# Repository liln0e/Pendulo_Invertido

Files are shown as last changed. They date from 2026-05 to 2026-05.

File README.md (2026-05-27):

# Péndulo Invertido Autocontrolado

Proyecto académico de un **péndulo invertido autocontrolado (self-balancing robot)** basado en **ESP32** y control **PID**, diseñado para mantener el equilibrio de forma autónoma mediante sensores inerciales y control en tiempo real.

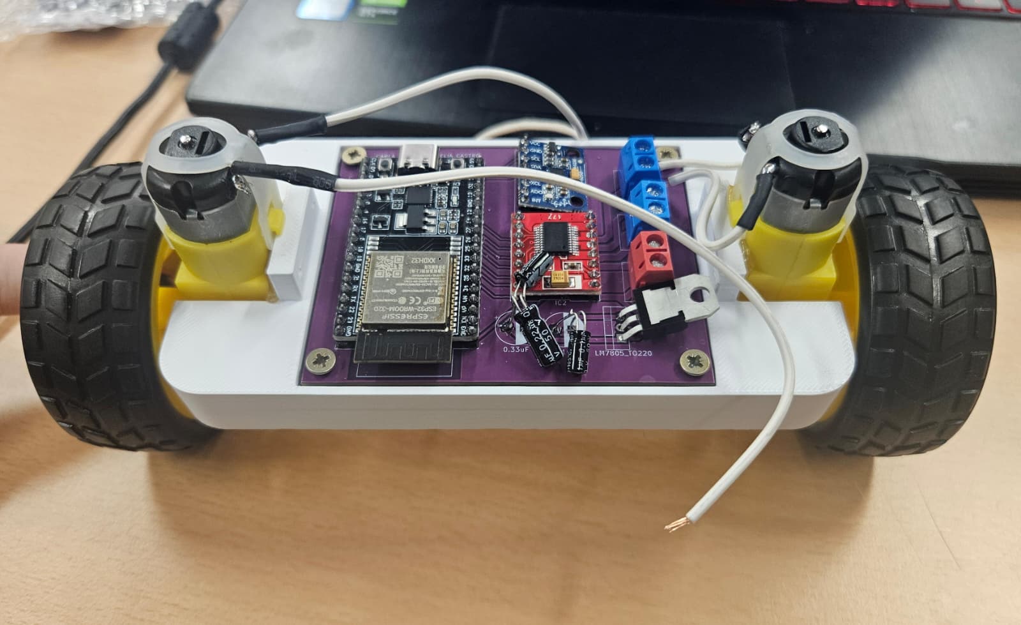
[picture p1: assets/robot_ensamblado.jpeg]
Robot ensamblado


---

## Descripción del proyecto

Este repositorio recoge el desarrollo de un **robot autoequilibrado de dos ruedas**, integrando diseño mecánico, electrónica y programación embebida.

El sistema utiliza un **ESP32** como unidad principal de control, un sensor **MPU6050** para estimar la inclinación y un controlador **PID** encargado de actuar sobre los motores para mantener el equilibrio.

El proyecto incluye:

- Diseño mecánico del chasis mediante modelado 3D.
- Diseño electrónico mediante una PCB personalizada en **KiCad**.
- Programación embebida sobre **ESP32**.
- Implementación de control **PID** para estabilidad del sistema.

---

## Tecnologías utilizadas

### Hardware

- ESP32 DevKitC  
- MPU6050  
- TB6612FNG  
- LM7805  
- Motores DC con reductora  
- PCB personalizada  
- Chasis impreso en 3D  

### Software y herramientas

- ESP32 / Arduino Framework  
- KiCad  
- Fusion 360  
- Control PID discreto  
- Filtro complementario  

---

## Estructura del repositorio

```txt
Proyecto_Pendulo_Invertido/
│
├── README.md
├── costes.md
├── documentacion.md
│
├── assets/
├── electronica/
├── mecanica/
└── software/
```

### Documentación principal

- [`documentacion.md`](./documentacion.md) → Explicación técnica completa del sistema.
- [`costes.md`](./costes.md) → Coste aproximado de materiales y componentes.

### Carpetas del proyecto

- [`electronica/`](./electronica/) → Diseño PCB y archivos de KiCad.
- [`mecanica/`](./mecanica/) → Diseño del chasis y fabricación.
- [`software/`](./software/) → Código del sistema de control.
- [`assets/`](./assets/) → Recursos visuales del proyecto.

---

## Integrantes del proyecto

### Carla Freire Muíño  
GitHub: [@carlafreeire](https://github.com/carlafreeire)

### Noelia Castro Rodríguez  
GitHub: [@liln0e](https://github.com/liln0e)

---

## Licencia

Proyecto desarrollado con fines académicos y educativos.

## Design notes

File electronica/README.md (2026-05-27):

# Diseño electrónico del péndulo invertido

Esta carpeta contiene los archivos del diseño electrónico del **péndulo invertido autocontrolado**, desarrollados en **KiCad**.

## Contenido

- `Pendulo_Inverso.kicad_sch` → Esquemático electrónico del sistema.
- `Pendulo_Inverso.kicad_pcb` → Diseño de la PCB.
- `Pendulo_Inverso.kicad_pro` → Proyecto completo de KiCad.

## Descripción

La electrónica integra los principales componentes del robot:

- **ESP32 DevKitC** como unidad de control.
- **MPU6050** para la medición de inclinación.
- **TB6612FNG** para el control de motores.
- **LM7805** para regulación de tensión.
- Conectores de alimentación y motores.

El diseño fue realizado sobre una **PCB personalizada** con el objetivo de reducir cableado, facilitar el ensamblaje y mejorar la integración del sistema.

La explicación técnica detallada puede consultarse en [`../documentacion.md`](../documentacion.md).

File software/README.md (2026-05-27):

# Software del péndulo invertido

Esta carpeta contiene el código fuente del **péndulo invertido autocontrolado**, desarrollado para ejecutarse sobre un **ESP32 DevKitC**.

## Contenido

- `PID_Basico.ino` → Implementación de un controlador PID discreto básico.
- `PID_IIR.ino` → Implementación del PID en forma de filtro IIR.
- `PID_Filtrado.ino` → Implementación del PID con filtrado en el término derivativo.

## Funcionalidades implementadas

- Lectura del sensor **MPU6050**.
- Estimación del ángulo de inclinación.
- Filtrado de señal mediante filtro complementario.
- Control PID discreto.
- Generación de señales para motores DC.
- Ajuste y depuración mediante monitor serie.

Durante el desarrollo se implementaron distintas versiones del controlador para comparar estabilidad, suavidad de respuesta y sensibilidad al ruido.

La arquitectura completa del sistema se describe en [`../documentacion.md`](../documentacion.md).

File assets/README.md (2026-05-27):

# Recursos visuales del proyecto

En esta carpeta se incluyen recursos visuales empleados para documentar el desarrollo del **péndulo invertido autocontrolado**, mostrando distintas fases del diseño electrónico, fabricación y ensamblaje del sistema.

## Contenido

Los siguientes archivos corresponden a material visual del proyecto:

- `esquematico_kicad.jpg` → Esquemático electrónico del sistema realizado en KiCad.
- `pcb_diseno_kicad.png` → Diseño de la PCB realizado en KiCad.
- `pcb_fabricada.jpeg` → PCB fabricada tras el proceso de producción.
- `montaje_componentes.jpeg` → Integración de los principales componentes electrónicos sobre el chasis.
- `robot_ensamblado.jpeg` → Estado del robot completamente ensamblado.

## Descripción

Los recursos visuales permiten documentar la evolución del proyecto desde el diseño electrónico hasta el montaje final del sistema.

Las imágenes incluidas muestran distintas etapas del desarrollo:

- Diseño del esquemático electrónico del sistema en KiCad, incluyendo el **ESP32**, el controlador de motores **TB6612FNG**, el sensor **MPU6050** y la etapa de alimentación.
- Diseño y distribución de componentes en la PCB.
- Fabricación de la placa electrónica.
- Integración de la electrónica sobre el chasis impreso en 3D.
- Ensamblaje del sistema completo con motores, ruedas y electrónica de control.

Este material se emplea como apoyo visual de la documentación técnica del proyecto y permite mostrar de forma clara el proceso de diseño, fabricación e integración del péndulo invertido.

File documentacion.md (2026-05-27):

# Documentación técnica del proyecto

Este documento recoge la información técnica general del proyecto de **péndulo invertido autocontrolado (self-balancing robot)**, incluyendo la arquitectura del sistema, el diseño mecánico, la electrónica y el software implementado para el control del robot.

El objetivo principal del sistema es mantener el equilibrio de forma autónoma mediante un controlador **PID**, capaz de corregir la inclinación del robot actuando sobre los motores en tiempo real.

---

# Arquitectura general del sistema

El robot implementa un sistema de control en lazo cerrado compuesto por las siguientes etapas:

1. **Captura de inclinación** mediante una unidad IMU (**MPU6050**).
2. **Estimación del ángulo** utilizando acelerómetro y giroscopio.
3. **Filtrado de señal** mediante un **filtro complementario**.
4. **Cálculo de la acción de control PID**.
5. **Actuación sobre los motores** para recuperar la posición vertical.

El flujo simplificado del sistema es el siguiente:

```txt
MPU6050
    ↓
Estimación del ángulo
    ↓
Filtro complementario
    ↓
Control PID
    ↓
Driver TB6612FNG
    ↓
Motores
    ↓
Corrección de la inclinación
```

El sistema realiza un procesamiento continuo de los datos de inclinación y ajusta dinámicamente la velocidad de los motores para compensar perturbaciones y mantener la estabilidad.

---

# Diseño mecánico

La parte mecánica del robot se diseñó con el objetivo de obtener una estructura **compacta, ligera y estable**, favoreciendo un **centro de gravedad bajo** para mejorar el comportamiento dinámico del sistema.

El chasis fue modelado en **Fusion 360** y fabricado mediante **impresión 3D**, permitiendo adaptar la geometría a las necesidades específicas del proyecto y facilitar la integración de los componentes electrónicos.

Durante el desarrollo se realizaron distintas iteraciones del diseño para optimizar:

- Distribución del peso.
- Posicionamiento de la electrónica.
- Integración de motores y ruedas.
- Robustez estructural.
- Facilidad de ensamblaje.

El diseño final permite alojar de forma compacta todos los elementos del sistema, manteniendo un acceso sencillo a la electrónica y facilitando futuras modificaciones.

---

# Diseño electrónico

La electrónica del robot fue diseñada sobre una **PCB personalizada desarrollada en KiCad**, permitiendo integrar los distintos módulos del sistema en una única placa.

Los componentes principales utilizados son:

- **ESP32 DevKitC** → Unidad principal de control.
- **MPU6050** → Sensor IMU para estimación de inclinación.
- **TB6612FNG** → Driver de control de motores.
- **LM7805** → Regulación de tensión.
- Conectores de alimentación y motores.

El diseño electrónico se planteó con varios objetivos:

- Reducir el cableado del sistema.
- Mejorar la integración entre componentes.
- Facilitar el ensamblaje del robot.
- Incrementar la robustez del conjunto.

La PCB integra alimentación, control y conexiones de potencia necesarias para el funcionamiento autónomo del sistema.

---

# Diseño software

El software del robot se ejecuta sobre una **ESP32**, encargándose de procesar la información procedente del sensor y aplicar la lógica de control necesaria para mantener el equilibrio.

Las funcionalidades principales implementadas son:

- Lectura del sensor **MPU6050**.
- Estimación del ángulo de inclinación.
- Aplicación de un **filtro complementario**.
- Implementación del **control PID discreto**.
- Generación de señales de control para los motores.
- Ajuste y depuración mediante monitor serie.

Durante el desarrollo se implementaron distintas versiones del controlador PID con el objetivo de comparar comportamiento, estabilidad y sensibilidad al ruido del sistema.

La lógica simplificada del software es:

```txt
Lectura IMU
    ↓
Estimación de inclinación
    ↓
Filtro complementario
    ↓
Cálculo PID
    ↓
Control de motores
    ↓
Corrección del equilibrio
```

---

# Organización del repositorio

El proyecto se organiza en distintas carpetas para separar la documentación y facilitar el desarrollo:

```txt
Proyecto_Pendulo_Invertido/
│
├── README.md
├── costes.md
├── documentacion.md
│
├── assets/
├── electronica/
├── mecanica/
└── software/
```

Cada carpeta contiene información específica del proyecto:

- `electronica/` → Diseño PCB, esquemáticos y archivos de KiCad.
- `mecanica/` → Modelado 3D y archivos de fabricación.
- `software/` → Código fuente y pruebas del controlador.
- `assets/` → Recursos visuales del proyecto.

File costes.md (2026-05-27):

# Costes y materiales

En este documento se recoge el coste aproximado de los materiales empleados para la construcción del robot tipo **péndulo invertido (self-balancing robot)**.

El objetivo del proyecto fue desarrollar un sistema funcional utilizando **componentes económicos y fácilmente accesibles**, complementados con recursos proporcionados por la universidad, como la impresión 3D y parte del material electrónico.

---

# Desglose de materiales

| Componente | Cantidad | Precio (€) | Comentarios |
|---|---|---|---|
| **ESP32 DevKitC** | 1 | 4,49 | Microcontrolador principal |
| **MPU6050 (GY-521)** | 1 | 1,81 | Sensor IMU (acelerómetro + giroscopio) |
| **Motores TT + ruedas** | 2 motores + 2 ruedas | 3,99 | Sistema de tracción |
| **Driver TB6612FNG** | 1 | Incluido | Control de motores |
| **LM7805** | 1 | 1,45 | Regulador de tensión |
| **PCB personalizada (JLCPCB)** | 1 | ≈ 2,87 | Coste real aproximado por unidad |
| **Pila plana 3R12 4,5 V** | 1 | 5,99 | Alimentación del sistema |
| **Condensador 0.1 µF** | 1 | 0,00 | Material de laboratorio |
| **Condensador equivalente 0.33 µF** | 1 conjunto | 0,00 | Implementado con 0.22 µF + 0.11 µF |
| **Borneras de 2 pines** | 3 | 0,00 | Material de laboratorio |
| **Chasis impreso 3D** | 1 | 0,00 | Fabricado en la universidad |

---

# Coste total aproximado

Considerando únicamente los materiales realmente utilizados en el robot:

**Coste estimado total del proyecto:** **≈ 20,60 €**

> Este valor no incluye material proporcionado gratuitamente por la universidad ni costes indirectos de fabricación.

---

# Notas

- La **PCB fue diseñada específicamente para el proyecto** y fabricada mediante **JLCPCB**. El coste reflejado corresponde a una unidad individual del pedido realizado.
- El condensador de **0.33 µF no estaba disponible**, por lo que se implementó correctamente conectando **0.22 µF y 0.11 µF en paralelo**.
- El **chasis fue diseñado e impreso en 3D en la universidad**, reduciendo significativamente el coste total del proyecto.
- Se priorizó el uso de **componentes económicos y reutilizables**, manteniendo un equilibrio entre funcionalidad y bajo coste.

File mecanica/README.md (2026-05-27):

# Diseño mecánico del péndulo invertido

Esta carpeta contiene los archivos relacionados con el diseño mecánico del **péndulo invertido autocontrolado**, incluyendo el chasis y los modelos preparados para fabricación.

## Contenido

- `pendulo_invertido.3mf` → Modelo 3D editable del chasis.
- `pendulo_invertido.gcode` → Archivo preparado para impresión 3D.

## Descripción

El chasis fue diseñado en **Fusion 360** y fabricado mediante **impresión 3D**, buscando:

- Centro de gravedad bajo.
- Distribución equilibrada del peso.
- Integración compacta de la electrónica.
- Facilidad de ensamblaje.

La documentación técnica completa se encuentra en [`../documentacion.md`](../documentacion.md).

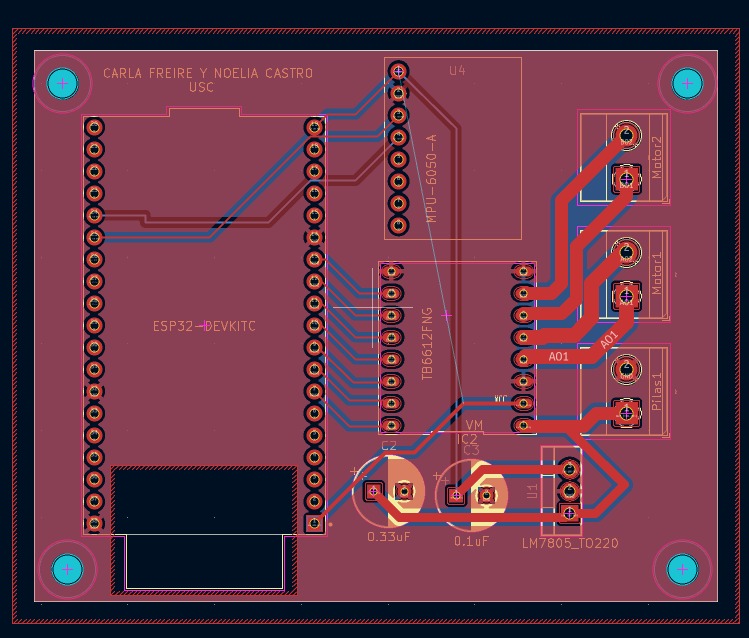
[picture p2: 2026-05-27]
assets/pcb_diseno_kicad.jpeg

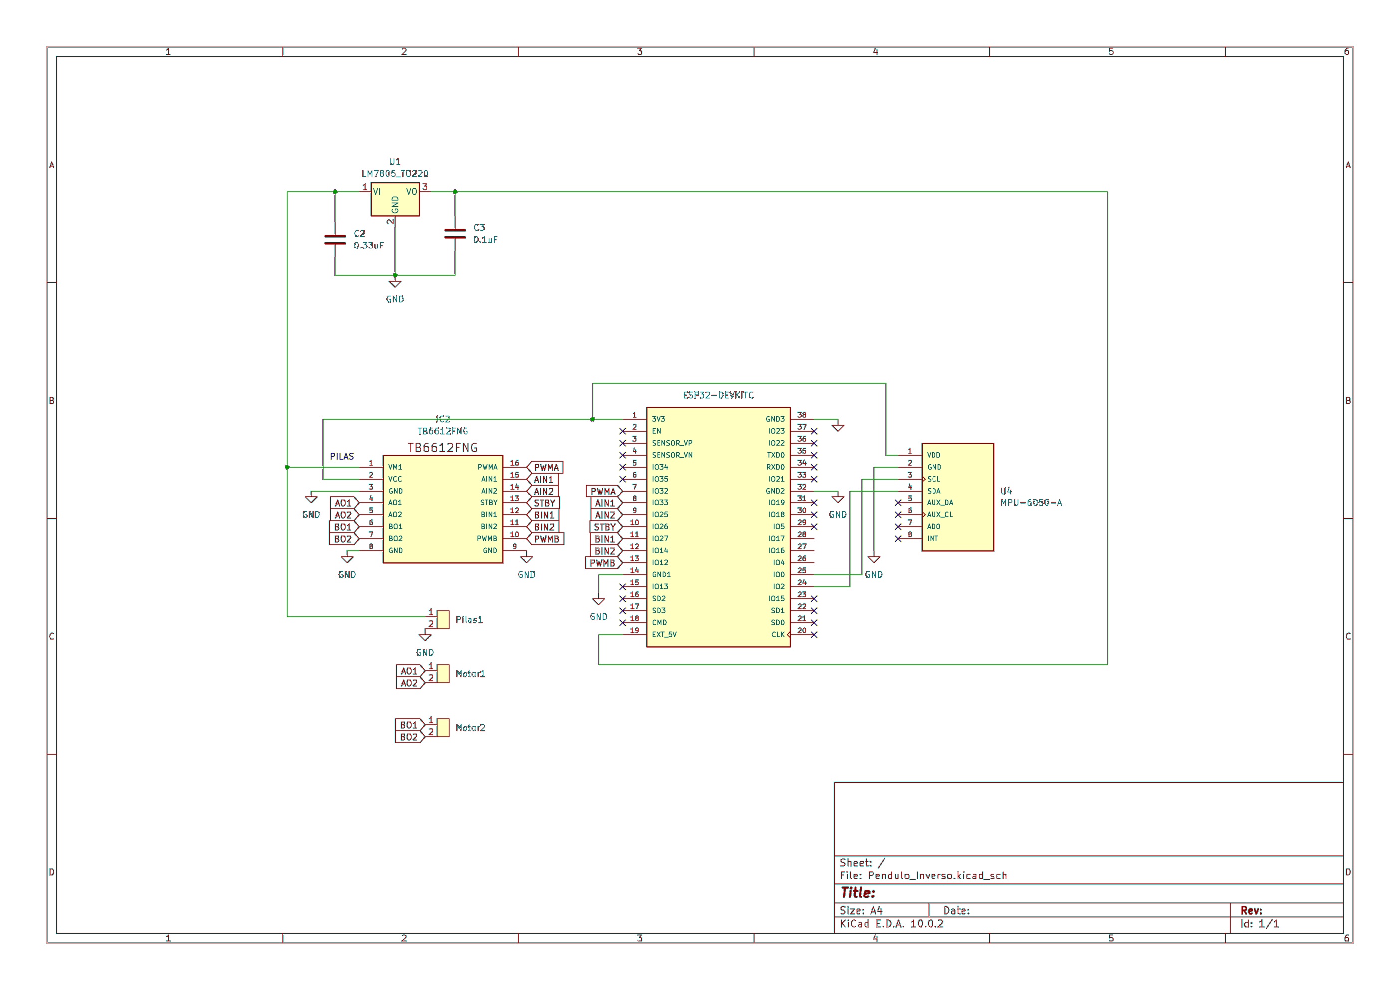
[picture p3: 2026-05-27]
assets/esquematico_kicad.jpg

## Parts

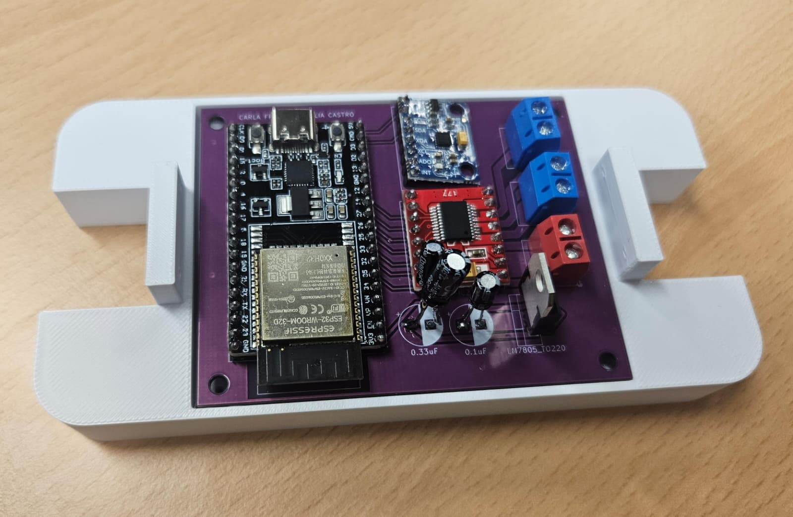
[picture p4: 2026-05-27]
assets/montaje_componentes.jpeg

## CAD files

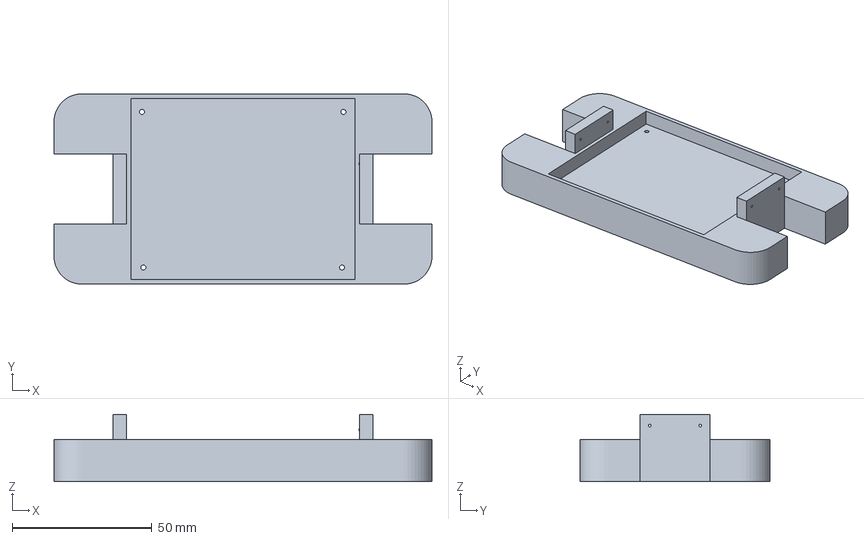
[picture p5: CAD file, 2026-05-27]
mecanica/pendulo_invertido.3mf
135.0 x 68.0 x 24.0 mm

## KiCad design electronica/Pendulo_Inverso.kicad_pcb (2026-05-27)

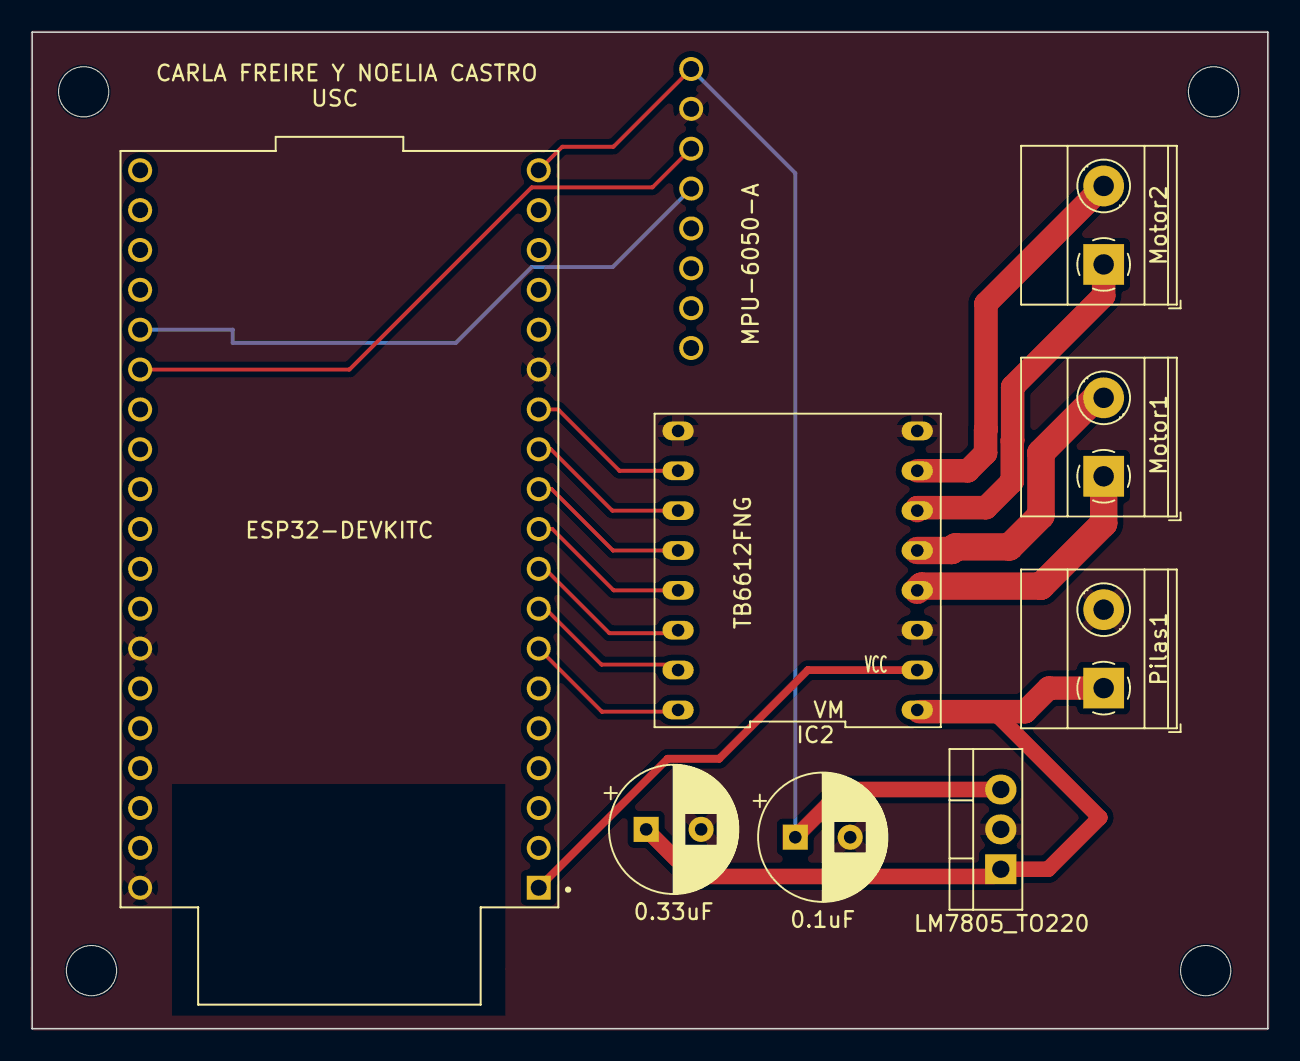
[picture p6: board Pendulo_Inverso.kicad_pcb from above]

Board: 2 copper layers, 78.7 x 63.5 mm, 9 parts (0 on the bottom side), 17 nets.

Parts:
C2: 0.33uF; CP_Radial_D8.0mm_P3.50mm
C3: 0.1uF; CP_Radial_D8.0mm_P3.50mm
IC2: TB6612FNG; TB6612FngSparkfun
Motor1, Motor2: TerminalBlock_Phoenix_MKDS-1,5-2_1x02_P5.00mm_Horizontal
Pilas1: TerminalBlock_Phoenix_MKDS-1,5-2_1x02_P5.00mm_Horizontal
U1: LM7805_TO220; TO-220-3_Vertical
U2: ESP32-DEVKITC; MODULE_ESP32-DEVKITC
U4: MPU-6050-A; MPU6050

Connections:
AIN1: IC2.15 (AIN1), U2.8 (IO33)
AIN2: IC2.14 (AIN2), U2.9 (IO25)
AO1: IC2.4 (AO1), Motor1.1
AO2: IC2.5 (AO2), Motor1.2
BIN1: IC2.12 (BIN1), U2.11 (IO27)
BIN2: IC2.11 (BIN2), U2.12 (IO14)
BO1: IC2.6 (BO1), Motor2.1
BO2: IC2.7 (BO2), Motor2.2
GND: C2.2, C3.2, IC2.3 (GND), IC2.8 (GND), IC2.9 (GND), Pilas1.2, U1.2 (GND), U2.14 (GND1), U2.32 (GND2), U2.38 (GND3), U4.2 (GND)
unnamed: IC2.2 (VCC), U2.1 (3V3), U4.1 (VDD)
unnamed: C2.1, IC2.1 (VM1), Pilas1.1, U1.1 (VI)
unnamed: C3.1, U1.3 (VO), U2.19 (EXT_5V)
unnamed: U2.25 (IO0), U4.3 (SCL)
unnamed: U2.24 (IO2), U4.4 (SDA)
PWMA: IC2.16 (PWMA), U2.7 (IO32)
PWMB: IC2.10 (PWMB), U2.13 (IO12)
STBY: IC2.13 (STBY), U2.10 (IO26)

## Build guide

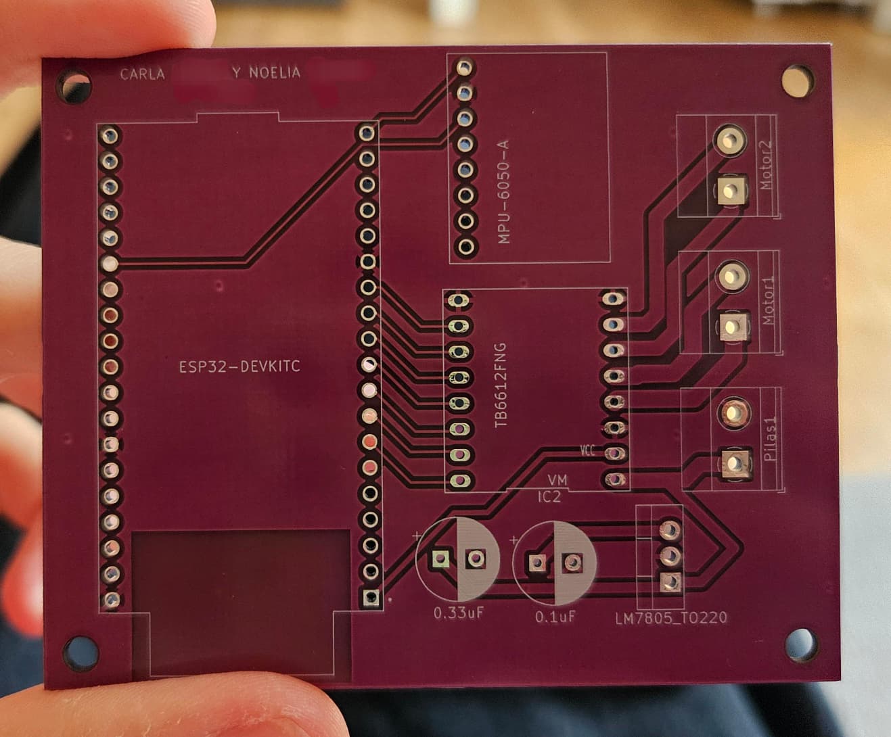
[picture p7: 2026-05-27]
assets/pcb_fabricada.jpeg

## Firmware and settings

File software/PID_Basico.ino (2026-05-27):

#include <Wire.h>
#include <MPU6050.h>

MPU6050 mpu;

// ======================
// PINES ESP32
// ======================

// Pines I2C del MPU6050
#define SDA_PIN 32
#define SCL_PIN 33

// Pines del driver TB6612FNG
#define PWMA 16
#define AIN2 17
#define AIN1 18

#define PWMB 22
#define BIN1 19
#define BIN2 21

#define STBY 23

// Configuración PWM del ESP32
const int freq = 20000;
const int resolution = 8;

const int channelA = 0;
const int channelB = 1;

// ======================
// VARIABLES MPU6050
// ======================

float accAngle = 0;
float gyroRate = 0;
float angle = 0;

unsigned long prevTime = 0;

// ======================
// PID BÁSICO
// ======================

// El setPoint es el ángulo deseado.
// Para el péndulo invertido, el equilibrio está en 0 grados.
float setPoint = 0.0;

// Valores iniciales del PID.
// Estos valores se tienen que ajustar probando el robot real.
float Kp = 18.0;
float Ki = 0.0;
float Kd = 0.8;

float error = 0;
float previousError = 0;
float integral = 0;
float derivative = 0;

float output = 0;

// Límites de PWM
int minPWM = 35;
int maxPWM = 255;

// ======================
// SETUP
// ======================

void setup() {

  Serial.begin(115200);

  // Iniciamos comunicación I2C con el MPU6050.
  Wire.begin(SDA_PIN, SCL_PIN);

  // Inicializamos el sensor.
  mpu.initialize();

  if (mpu.testConnection()) {
    Serial.println("MPU6050 conectado correctamente");
  } else {
    Serial.println("Error al conectar el MPU6050");
    while (1);
  }

  // Configuración de pines del driver de motores.
  pinMode(AIN1, OUTPUT);
  pinMode(AIN2, OUTPUT);
  pinMode(BIN1, OUTPUT);
  pinMode(BIN2, OUTPUT);
  pinMode(STBY, OUTPUT);

  // Activamos el driver.
  digitalWrite(STBY, HIGH);

  // Configuración PWM del ESP32.
  ledcSetup(channelA, freq, resolution);
  ledcSetup(channelB, freq, resolution);

  ledcAttachPin(PWMA, channelA);
  ledcAttachPin(PWMB, channelB);

  stopMotors();

  delay(1000);

  prevTime = millis();

  Serial.println("Sistema listo - PID basico");
}

// ======================
// LOOP PRINCIPAL
// ======================

void loop() {

  int16_t ax, ay, az;
  int16_t gx, gy, gz;

  // Leemos acelerómetro y giroscopio.
  mpu.getMotion6(&ax, &ay, &az, &gx, &gy, &gz);

  // Calculamos el tiempo de muestreo.
  unsigned long currentTime = millis();
  float dt = (currentTime - prevTime) / 1000.0;
  prevTime = currentTime;

  // Protección por si dt sale cero.
  if (dt <= 0) dt = 0.001;

  // ======================
  // CÁLCULO DEL ÁNGULO
  // ======================

  // Ángulo obtenido con el acelerómetro.
  accAngle = atan2(ay, az) * 180 / PI;

  // Velocidad angular del giroscopio.
  // El factor 131 depende de la escala usada por el MPU6050.
  gyroRate = gx / 131.0;

  // Filtro complementario.
  // Se usa principalmente el giroscopio, pero el acelerómetro corrige la deriva.
  angle = 0.98 * (angle + gyroRate * dt) + 0.02 * accAngle;

  // ======================
  // SEGURIDAD
  // ======================

  // Si el robot se inclina demasiado, se paran los motores.
  if (abs(angle) > 45) {
    stopMotors();

    // Reinicio del PID para que no se acumule integral al estar caído.
    integral = 0;
    previousError = 0;

    return;
  }

  // ======================
  // PID DISCRETO BÁSICO
  // ======================

  // Error entre el ángulo deseado y el ángulo medido.
  error = setPoint - angle;

  // Parte integral.
  // Se suma el error multiplicado por el tiempo de muestreo.
  integral += error * dt;

  // Limitamos la integral para evitar wind-up.
  integral = constrain(integral, -100, 100);

  // Parte derivativa.
  // Se calcula la variación del error entre dos muestras.
  derivative = (error - previousError) / dt;

  // Salida total del PID.
  output = Kp * error + Ki * integral + Kd * derivative;

  // Guardamos el error actual para el siguiente ciclo.
  previousError = error;

  // Aplicamos la salida del PID a los motores.
  moveMotors(output);

  // Datos por serial para observar el comportamiento.
  Serial.print("Angle: ");
  Serial.print(angle);

  Serial.print(" | Error: ");
  Serial.print(error);

  Serial.print(" | PID basico: ");
  Serial.println(output);

  delay(5);
}

// ======================
// CONTROL DE MOTORES
// ======================

void moveMotors(float speed) {

  int pwm = abs(speed);

  pwm = constrain(pwm, 0, maxPWM);

  // Los motores no se mueven bien con valores muy bajos,
  // por eso se fuerza un PWM mínimo.
  if (pwm > 0 && pwm < minPWM) {
    pwm = minPWM;
  }

  if (speed > 0) {

    digitalWrite(AIN1, HIGH);
    digitalWrite(AIN2, LOW);

    digitalWrite(BIN1, HIGH);
    digitalWrite(BIN2, LOW);

    ledcWrite(channelA, pwm);
    ledcWrite(channelB, pwm);
  }

  else if (speed < 0) {

    digitalWrite(AIN1, LOW);
    digitalWrite(AIN2, HIGH);

    digitalWrite(BIN1, LOW);
    digitalWrite(BIN2, HIGH);

    ledcWrite(channelA, pwm);
    ledcWrite(channelB, pwm);
  }

  else {
    stopMotors();
  }
}

// ======================
// PARAR MOTORES
// ======================

void stopMotors() {

  ledcWrite(channelA, 0);
  ledcWrite(channelB, 0);

  digitalWrite(AIN1, LOW);
  digitalWrite(AIN2, LOW);

  digitalWrite(BIN1, LOW);
  digitalWrite(BIN2, LOW);
}

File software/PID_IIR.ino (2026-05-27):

#include <Wire.h>
#include <MPU6050.h>

MPU6050 mpu;

// ======================
// PINES ESP32
// ======================

#define SDA_PIN 32
#define SCL_PIN 33

#define PWMA 16
#define AIN2 17
#define AIN1 18

#define PWMB 22
#define BIN1 19
#define BIN2 21

#define STBY 23

const int freq = 20000;
const int resolution = 8;

const int channelA = 0;
const int channelB = 1;

// ======================
// VARIABLES MPU6050
// ======================

float accAngle = 0;
float gyroRate = 0;
float angle = 0;

unsigned long prevTime = 0;

// ======================
// PID COMO FILTRO IIR
// ======================

float setPoint = 0.0;

// Ganancias iniciales.
// Se pueden cambiar según las pruebas del robot.
float Kp = 18.0;
float Ki = 0.0;
float Kd = 0.8;

// Errores actual y anteriores.
float error0 = 0;   // e(k)
float error1 = 0;   // e(k-1)
float error2 = 0;   // e(k-2)

// Coeficientes del PID discreto en forma IIR.
float A0 = 0;
float A1 = 0;
float A2 = 0;

// Salida del controlador.
float output = 0;

int minPWM = 35;
int maxPWM = 255;

// ======================
// SETUP
// ======================

void setup() {

  Serial.begin(115200);

  Wire.begin(SDA_PIN, SCL_PIN);

  mpu.initialize();

  if (mpu.testConnection()) {
    Serial.println("MPU6050 conectado correctamente");
  } else {
    Serial.println("Error al conectar el MPU6050");
    while (1);
  }

  pinMode(AIN1, OUTPUT);
  pinMode(AIN2, OUTPUT);
  pinMode(BIN1, OUTPUT);
  pinMode(BIN2, OUTPUT);
  pinMode(STBY, OUTPUT);

  digitalWrite(STBY, HIGH);

  ledcSetup(channelA, freq, resolution);
  ledcSetup(channelB, freq, resolution);

  ledcAttachPin(PWMA, channelA);
  ledcAttachPin(PWMB, channelB);

  stopMotors();

  delay(1000);

  prevTime = millis();

  Serial.println("Sistema listo - PID IIR");
}

// ======================
// LOOP PRINCIPAL
// ======================

void loop() {

  int16_t ax, ay, az;
  int16_t gx, gy, gz;

  mpu.getMotion6(&ax, &ay, &az, &gx, &gy, &gz);

  unsigned long currentTime = millis();
  float dt = (currentTime - prevTime) / 1000.0;
  prevTime = currentTime;

  if (dt <= 0) dt = 0.001;

  // ======================
  // CÁLCULO DEL ÁNGULO
  // ======================

  accAngle = atan2(ay, az) * 180 / PI;
  gyroRate = gx / 131.0;

  angle = 0.98 * (angle + gyroRate * dt) + 0.02 * accAngle;

  // ======================
  // SEGURIDAD
  // ======================

  if (abs(angle) > 45) {
    stopMotors();
    resetPID();
    return;
  }

  // ======================
  // PID EN FORMA IIR
  // ======================

  // Actualizamos los coeficientes con el dt real.
  actualizarCoeficientes(dt);

  // Desplazamos los errores.
  // Lo que antes era e(k-1) pasa a ser e(k-2), etc.
  error2 = error1;
  error1 = error0;

  // Error actual.
  error0 = setPoint - angle;

  // Ecuación recursiva:
  // u(k) = u(k-1) + A0 e(k) + A1 e(k-1) + A2 e(k-2)
  output = output + A0 * error0 + A1 * error1 + A2 * error2;

  moveMotors(output);

  Serial.print("Angle: ");
  Serial.print(angle);

  Serial.print(" | Error: ");
  Serial.print(error0);

  Serial.print(" | PID IIR: ");
  Serial.println(output);

  delay(5);
}

// ======================
// CÁLCULO DE COEFICIENTES
// ======================

void actualizarCoeficientes(float dt) {

  // Estos coeficientes salen de discretizar el PID continuo.
  A0 = Kp + Ki * dt + Kd / dt;
  A1 = -Kp - 2.0 * Kd / dt;
  A2 = Kd / dt;
}

// ======================
// REINICIO DEL CONTROLADOR
// ======================

void resetPID() {

  error0 = 0;
  error1 = 0;
  error2 = 0;

  output = 0;
}

// ======================
// CONTROL DE MOTORES
// ======================

void moveMotors(float speed) {

  int pwm = abs(speed);

  pwm = constrain(pwm, 0, maxPWM);

  if (pwm > 0 && pwm < minPWM) {
    pwm = minPWM;
  }

  if (speed > 0) {

    digitalWrite(AIN1, HIGH);
    digitalWrite(AIN2, LOW);

    digitalWrite(BIN1, HIGH);
    digitalWrite(BIN2, LOW);

    ledcWrite(channelA, pwm);
    ledcWrite(channelB, pwm);
  }

  else if (speed < 0) {

    digitalWrite(AIN1, LOW);
    digitalWrite(AIN2, HIGH);

    digitalWrite(BIN1, LOW);
    digitalWrite(BIN2, HIGH);

    ledcWrite(channelA, pwm);
    ledcWrite(channelB, pwm);
  }

  else {
    stopMotors();
  }
}

// ======================
// PARAR MOTORES
// ======================

void stopMotors() {

  ledcWrite(channelA, 0);
  ledcWrite(channelB, 0);

  digitalWrite(AIN1, LOW);
  digitalWrite(AIN2, LOW);

  digitalWrite(BIN1, LOW);
  digitalWrite(BIN2, LOW);
}

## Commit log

2026-05-27 Add electronic design documentation for inverted pendulum
    Added detailed documentation for the electronic design of the inverted pendulum project, including schematics, PCB design, and component integration.
2026-05-27 Enhance README with software details for inverted pendulum
    Added detailed documentation about the inverted pendulum software, including descriptions of various PID controller implementations and system functionalities.
2026-05-27 Add cost and materials documentation for robot project
    Document the estimated costs and materials for the self-balancing robot project, including a breakdown of components and total estimated cost.
2026-05-27 Agregar documentación técnica del proyecto
    Este documento proporciona una visión general del proyecto de péndulo invertido, incluyendo detalles sobre la arquitectura del sistema, diseño mecánico, electrónico y software. Se organizan los archi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
2026-05-27 Mejorar la documentación técnica del proyecto
    Se actualizó la documentación técnica del proyecto para mejorar la claridad y precisión de la información sobre el diseño mecánico, electrónico y software del robot péndulo invertido.
